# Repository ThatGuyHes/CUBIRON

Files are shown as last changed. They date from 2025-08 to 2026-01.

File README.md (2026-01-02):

# 🧊 Cubiron — DIY Tiny FDM 3D Printer

Cubiron is a DIY, compact FDM 3D printer designed for low-cost, small-format printing and hands-on learning. It's built entirely from open-source parts and the cheapest components available, using custom printable mechanics and Klipper firmware.

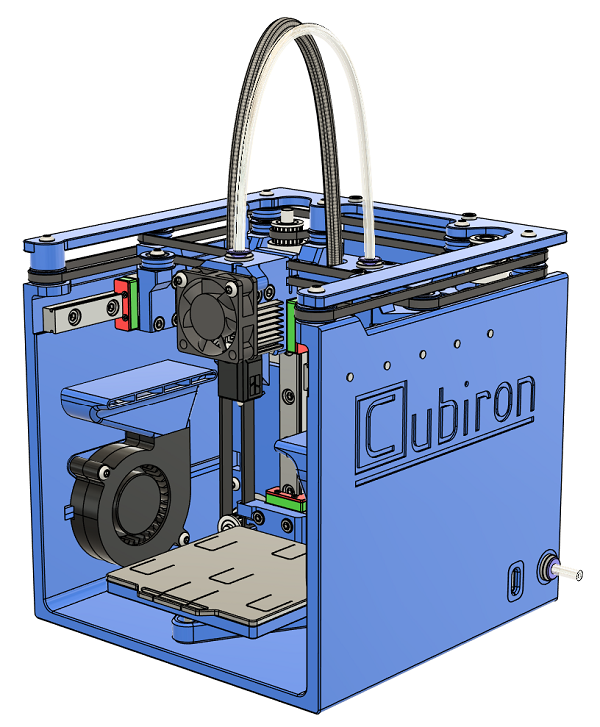
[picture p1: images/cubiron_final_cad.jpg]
Cubiron


---
## ✏️ Editor's Notes
- 03/09/2025: Added files for 1st public release.

---

## 🔧 Features

- 🔲 **70x70x65mm** Print Volume
- 📏 **144x145x148mm** Printer Size
- 🚀 Up to **500mm/s** and **10k mm/s²**
- 💧 **~10mm³ Flow** with PLA
- 🏷️ **~$270** Hardware cost
- 🧰 **1.5kg or 3.3lbs** Weight
- 🔌 **USB-C 20V**
- 💡 All 3d printed parts from **PETG**
- 📐 Includes **CAD files, BOM, STLs, printer.cfg**, and **slicer profiles**

---

## 📦 Included in this Repo

| Folder/File | Description |
|---|---|
| `CAD/` | Source and STEP files |
| `STLs/` | Printable parts |
| `firmware/` | Klipper config-files |
| `docs/` | Build manual, BOM |
| `LICENSE` | CERN-OHL-S v2 license |
| `README.md` | You're here! |

---

## 🛠 Specifications

| Feature | Value |
|---|---|
| Build Volume | 70 × 70 × 65 mm |
| Hotend Temp | Up to 230°C due to 20V |
| Drive Belts | 2GT, 3mm wide |
| Linear Rails | MGN9C - 100mm |
| Extruder | Hummingbird w/ HGX-Lite parts  |
| Hotend | BambuLab clone hotend |
| Board | Mellow Fly Micro4 |
| SBC | Raspberry Pi Zero 2W |
| Filament | PLA only |
| Print Bed | Cold, mechanical mount |
| Firmware | Klipper |
| Power Supply | USB-C PD 20V 100W |

---

## 🚧 Getting Started

0. **Read the "Printing Guidelines" section in the build guide!**
1. **3D print the STLs** in `STLs/`
2. **Follow the build guide** in `docs/build_manual.pdf`
3. **Flash Klipper** on your Pi Zero 2W
4. **Upload `printer.cfg`** and tune as needed

---

## 🙏 Acknowledgements

- Inspired by the DIY 3D printing community
- Thanks to the creators of Klipper, Hummingbird, and open hardware pioneers

---

## ❓ FAQ

<details>
  <summary>Are there any new plans for the Cubiron project?</summary>

  Not at the moment. Though I have some major changes in mind.
  Such as a 24V power supply, heated bed, and full enclosure.

</details>

---

## 💬 Contribute

This is a passion project — feedback, pull requests, remixes, and improvements are welcome!

---
## 🧾 License

Cubiron is licensed under the **CERN-OHL-S v2** license.

> This means you can use, modify, build, and sell it — but you must share changes under the same license.

📜 [Full License Text](LICENSE)



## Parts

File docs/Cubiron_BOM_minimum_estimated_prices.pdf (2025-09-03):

Part Name | Pieces | Price | Total Multiplier | Notes
LML9B Miniature Linear Rail | 5 | $7.52 | $37.60
Bambulab Clone Hotend | 1 | $8.25 | $8.25
Nema 14, 35mm long | 3 | $9.20 | $27.60
HGX-Lite hardware kit | 1 | $8.13 | $8.13
Nema 14 pancake 10t, 20mm long | 1 | $21.57 | $21.57
Mellow Fly Micro 4 | 1 | $27.66 | $27.66
RasPi Zero 2W | 1 | $23.31 | $23.31
100w USB-C PD charger 20V, 5A | 1 | $19.15 | $19.15
MP1584EN mini buck | 1 | $5.45 | $5.45
PDC004-PD 20V | 1 | $3.78 | $3.78
623-2RS 10pcs | 2 | $3.41 | $6.82
F623-RS 10pcs | 1 | $4.71 | $4.71
5015 Radial Fan 24V | 2 | $4.33 | $8.66
3010 Axial Fan 24V | 1 | $5.22 | $5.22
2GT-20T Pulley 5mm bore | 3 | $1.32 | $3.96
2GT 6mm Timing Belt 2m | 1 | $10.93 | $10.93
ECAS04 Bowden Coupling 4pcs | 1 | $1.41 | $1.41
M3x6 BHCS | 33 | | $0.00
M3x8 BHCS | 30 | | $0.00
M3x10 BHCS | 7 | | $0.00
M3x12 BHCS | 4 | | $0.00
M3x16 BHCS | 7 | | $0.00
M3x20 BHCS | 8 | | $0.00
M3x25 BHCS | 2 | | $0.00
M2.5x4 | 4 | | $0.00
M2x10 | 3 | | $0.00
M3x4 grub screw | 2 | | $0.00
M3 square nuts | 6 | $12.00 | $12.00 | * total for what's used
5x3x0.5mm spacers | 24 | | $0.00
PETG 1kg | 1 | $20.00 | $20.00
stranded wire 0.35mm² | 1 | | $0.00
stranded wire 0.25mm² | 1 | $5.00 | $5.00 | * total for what's used
spring 8x10x0.5mm 10pcs | 1 | $1.65 | $1.65
nylon braided wire sleeve 5mm, 1m | 1 | $1.75 | $1.75
PTFE tube 4mmOD, 2mmID 1m | 1 | $1.74 | $1.74
3M VHB Tape 2m | 1 | $2.36 | $2.36
Microswitch | 1 | $0.50 | $0.50
100x2.5mm zip ties 100pcs | 1 | $2.50 | $2.50
| | | $0.00
| | SUM | $271.71

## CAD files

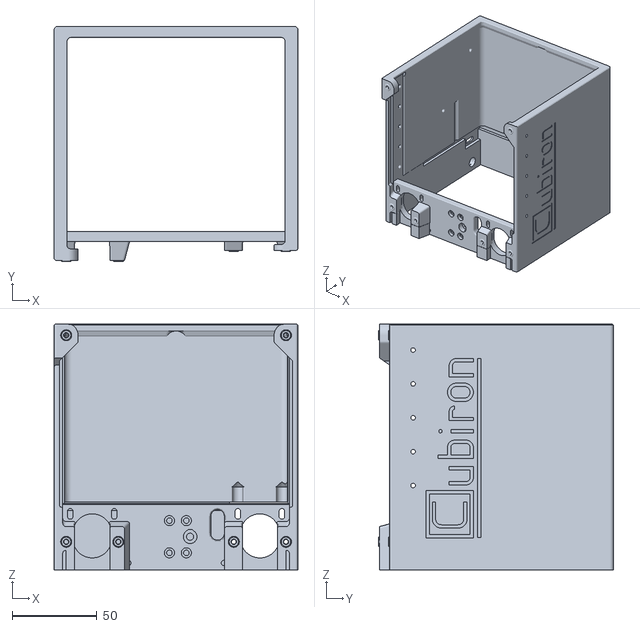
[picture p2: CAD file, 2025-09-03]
STLs/Main_frame.stl
144.1 x 138.8 x 145.0

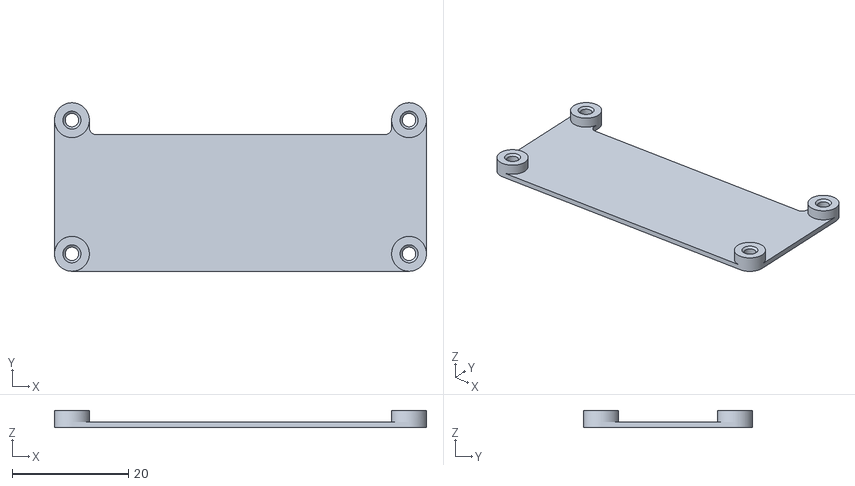
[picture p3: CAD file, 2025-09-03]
STLs/pi-zero_mount.stl
64.0 x 29.0 x 3.00

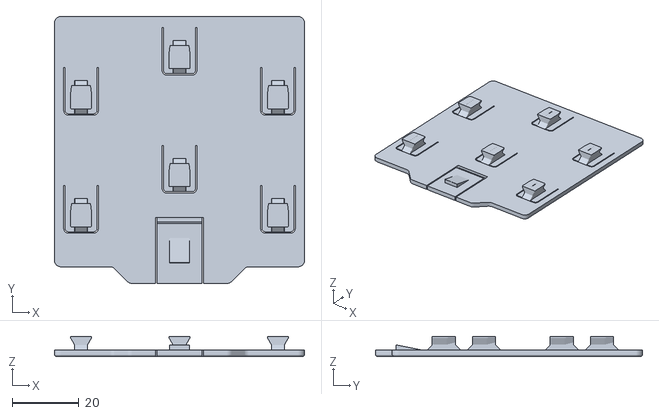
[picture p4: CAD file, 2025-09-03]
STLs/Bed-plate.stl
75.0 x 80.0 x 6.00

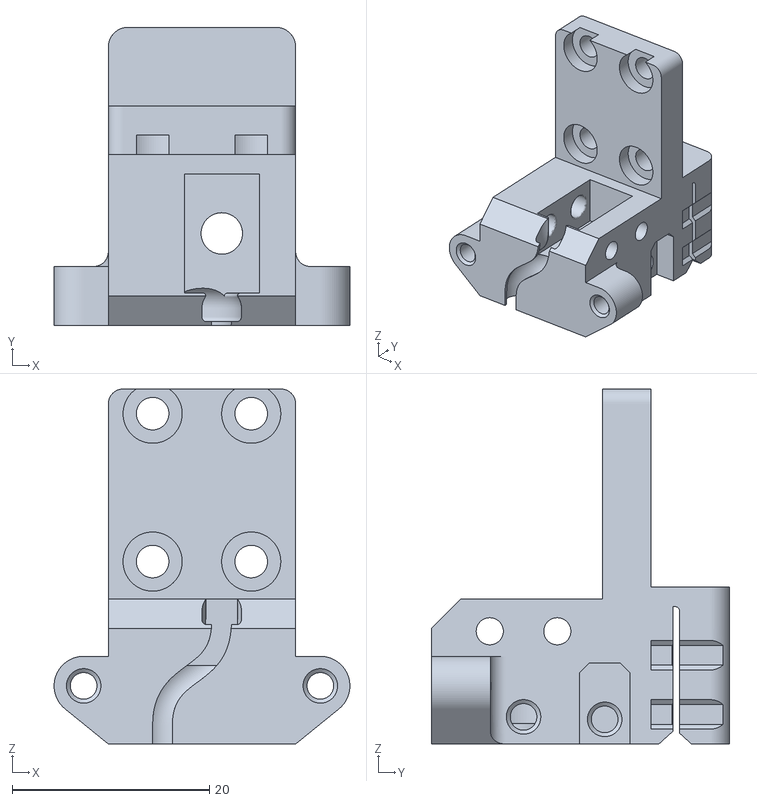
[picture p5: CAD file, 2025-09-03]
STLs/Print_head_frame.stl
30.0 x 30.3 x 36.0

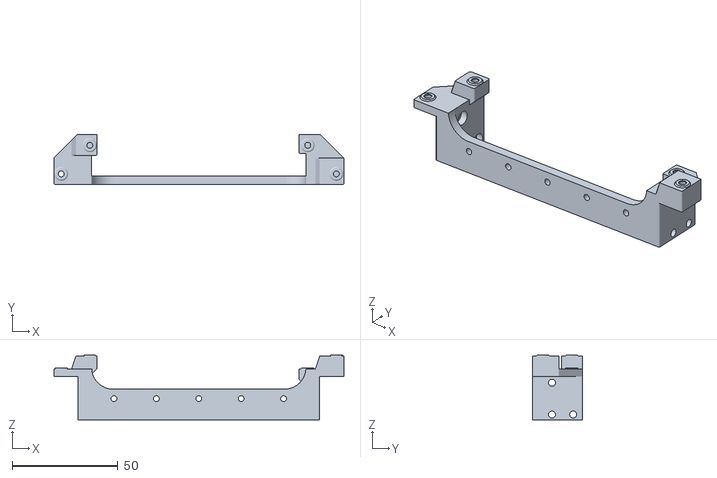
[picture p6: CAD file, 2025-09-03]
STLs/X_Beam.stl
136.8 x 23.7 x 30.5

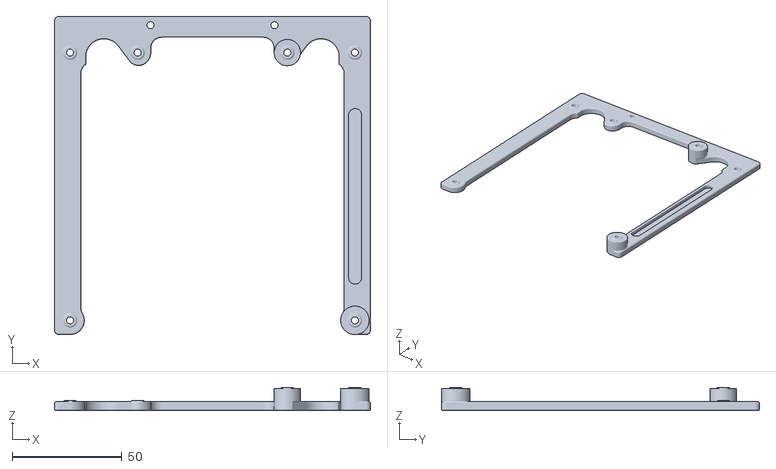
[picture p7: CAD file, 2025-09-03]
STLs/Top_Frame.stl
144.0 x 145.0 x 10.5

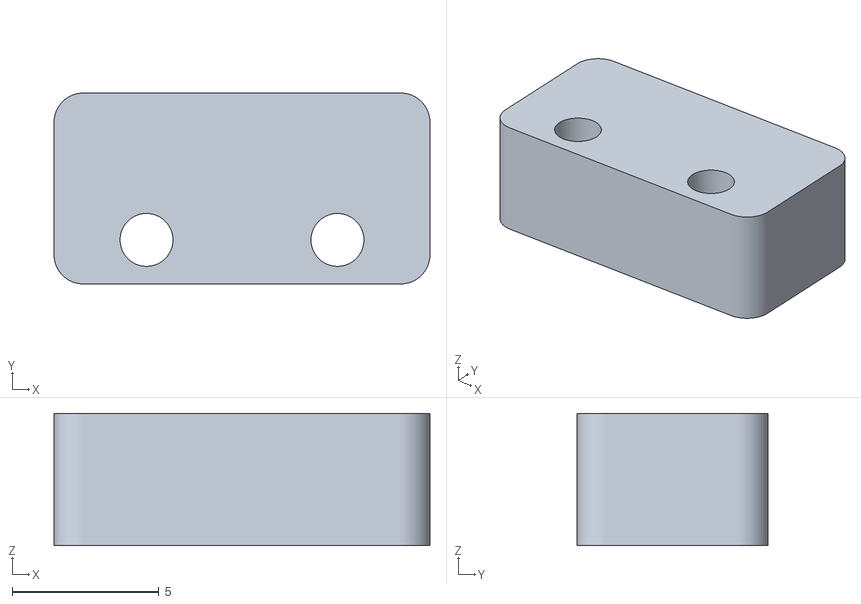
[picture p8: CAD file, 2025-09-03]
STLs/Z_endstop_mount.stl
12.8 x 6.50 x 4.50

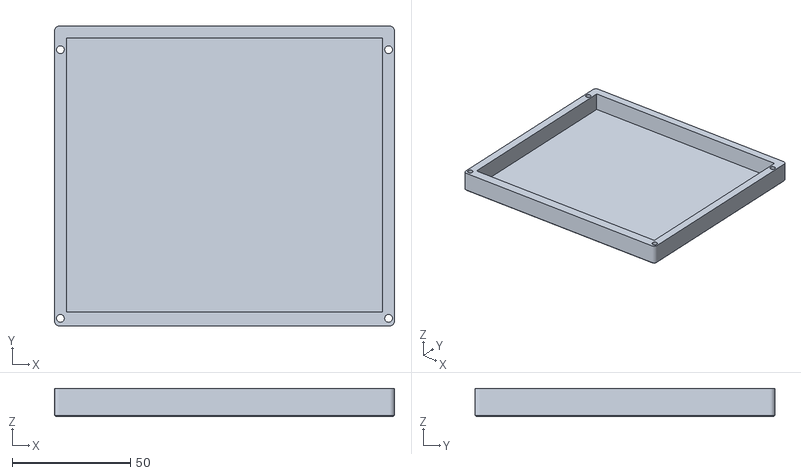
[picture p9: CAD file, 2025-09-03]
STLs/Electronics_cover.stl
144.0 x 127.0 x 12.0

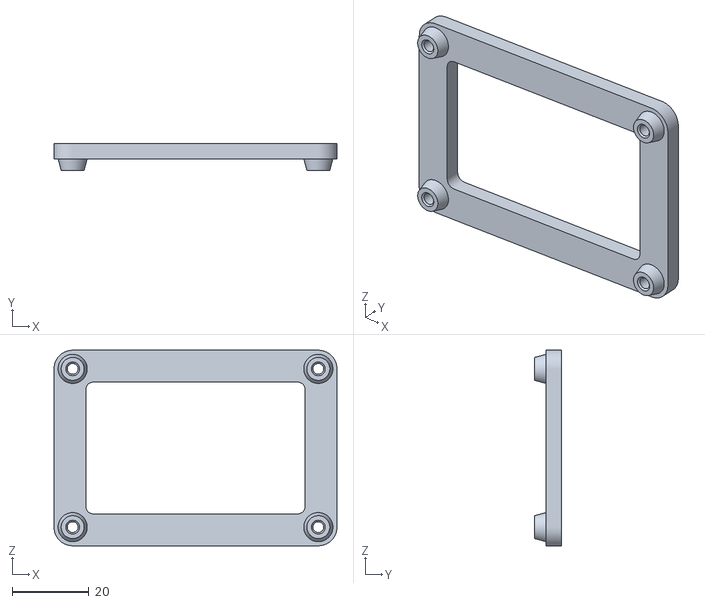
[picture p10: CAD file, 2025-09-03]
STLs/Micro4_Frame.stl
74.0 x 7.00 x 51.1

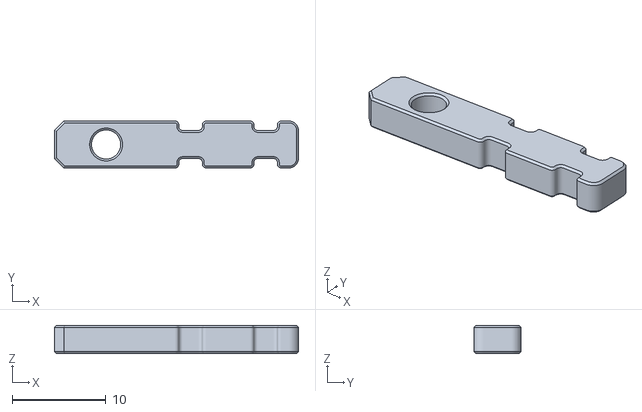
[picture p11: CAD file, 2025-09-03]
STLs/strain_reflief.stl
26.0 x 5.00 x 3.00

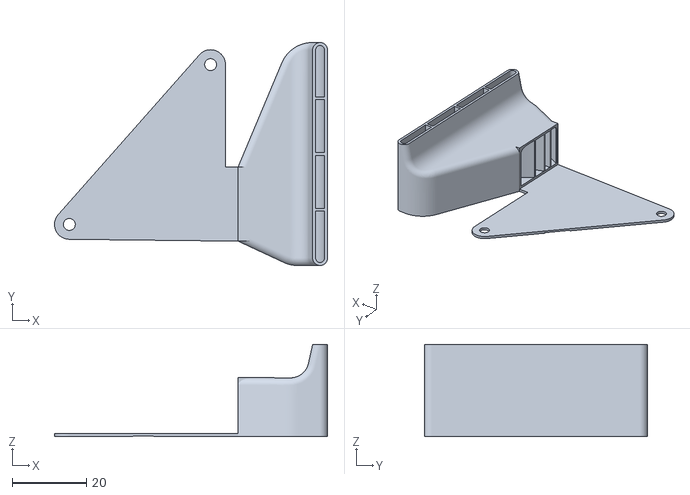
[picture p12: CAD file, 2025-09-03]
STLs/5015_fan_duct_2x.stl
73.4 x 60.0 x 24.8

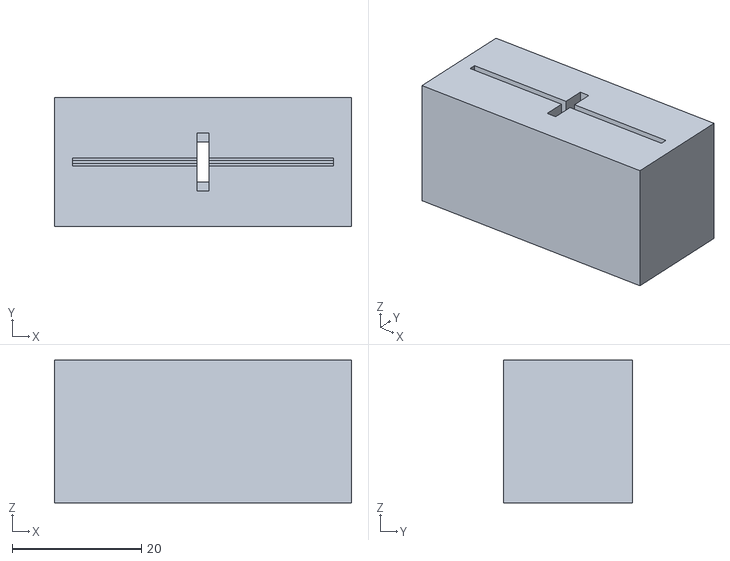
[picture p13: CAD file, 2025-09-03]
STLs/Positron 6mm to 3mm belt cutting jig.stl
46.0 x 20.0 x 22.1

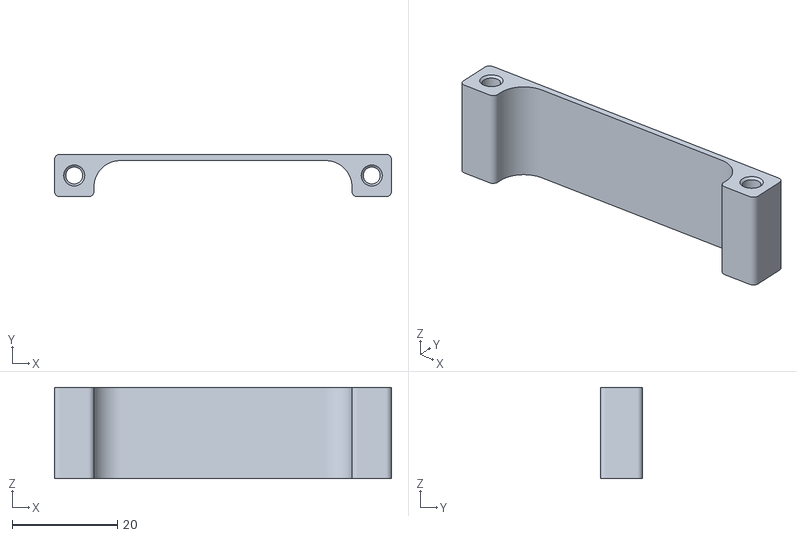
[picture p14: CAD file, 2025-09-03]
STLs/Handle.stl
64.0 x 8.05 x 17.4

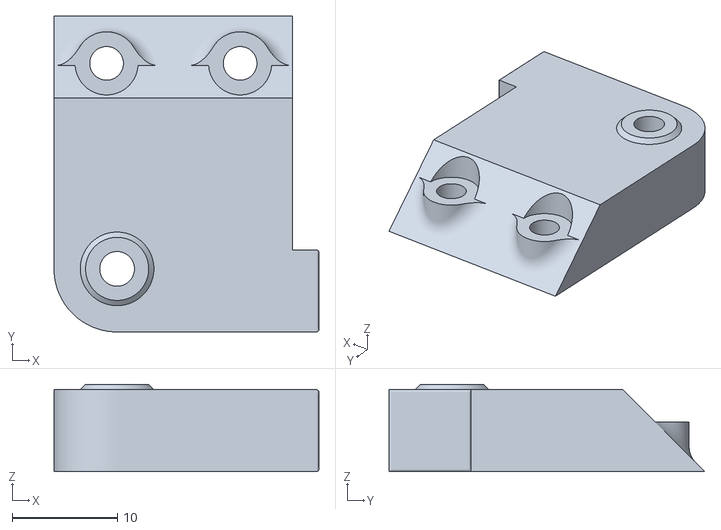
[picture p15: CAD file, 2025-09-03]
STLs/Z_Idler_Mount.stl
25.2 x 30.0 x 8.30

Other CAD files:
STLs/Z_axis_backplate.stl
STLs/X_Beam_supported.stl
STLs/Bed_Frame.stl
STLs/dc-dc-buck_cradle.stl
STLs/Bed_Frame_supported.stl
STLs/Printed_idler_24x.stl
STLs/Quickremove-bed.stl
STLs/Single-piece-idler.stl
STLs/Spacer_1mm_2x.stl
STLs/Thread_test_part.stl
STLs/USB-C-PD_cradle.stl

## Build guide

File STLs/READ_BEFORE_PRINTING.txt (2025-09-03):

**To print the Unibody main frame, please follow the instructions from the assembly manual in the "Printing Guidelines" section!**

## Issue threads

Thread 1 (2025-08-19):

Suggestions and Questions About Enclosure, Structural Strength, and Heated Bed Design

YueDayu, 2025-08-19:
Great project! I really like this kind of small 3D printer and I'm looking forward to its open-source release! However, I have a few questions:
* Is it possible to make the printer fully enclosed and add a built-in air filtration system?
* Is the strength of the front section sufficient? Would a crossbeam be needed for reinforcement?
* It looks like there is space for a heated bed. Is it possible to use a PCB to make an aluminum plate heated bed?

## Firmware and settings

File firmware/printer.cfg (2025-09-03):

####################################################################################
#                                         3D MELLOW                                #
####################################################################################
## Fly micro documentation: http://mellow.klipper.cn/#/board/fly_micro/README
## Fly micro schematic: http://mellow.klipper.cn/#/board/fly_micro/schematic
## FLY Official Taobao Store: https://shop126791347.taobao.com/shop/view_shop.htm?spm=a230r.1.14.4.1a4840a8hyvpPJ&user_number_id=2464680006
## For after-sales service, please contact Taobao customer service
## FLY After-sales Technical Support Group: 621032883
## FLY#RRF Firmware Group: 786561979

#####################################################################
#      Notes
#####################################################################
##***Things to change/check:***
## MCU path                                [mcu] 
## Printer movement range                   xyz position   
## Thermistor type                          [extruder] and [heater_bed]
## Z endstop position                       [safe_z_home] 
## Z endstop offset                         [stepper_z] 
## PID tuning                               [extruder] and [heater_bed] 
## Extruder motor steps fine-tuning         [extruder] 

#####################################################################
#      file invocation
#####################################################################
#[include fluidd.cfg]          # FLUIDD include file.
[include mainsail.cfg]        # MAINSAIL include file.
#Choose the file you need to use

#####################################################################
#      Master ID Configuration
#####################################################################
[mcu]
serial:
### To check USB firmware id: ls /dev/serial/by-id/*
### Replace /dev/serial/by-id/usb-Klipper_rp2040_MELLOW-if00 with your id
#canbus_uuid: 114514114514
### To check CAN firmware id: ~/klippy#env/bin/python ~/klipper/scripts/canbus_query.py can0
### For CAN, replace serial with canbus_uuid: and add the id

#####################################################################
#      Temperature monitoring
#####################################################################
[temperature_sensor Micro4]        # Show board temperature
sensor_type: temperature_mcu
#####################################################################
# [temperature_sensor lite2]       # Host temperature
# sensor_type: temperature_host
[temperature_sensor raspberry_pi]
sensor_type: temperature_host
min_temp: 10
max_temp: 100
#####################################################################
#      Kinematics and acceleration
#####################################################################
[printer]
kinematics: corexy
max_velocity: 500
max_accel: 5000
max_z_velocity: 15
max_z_accel: 300
square_corner_velocity: 6.0

[exclude_object]

#####################################################################
#      X/Y Stepper Settings
#####################################################################

[stepper_y]
## Refer to https://docs.vorondesign.com/build/startup/#v0
step_pin: gpio26
dir_pin:gpio25                                    # Check motor direction in link above. If inverted, add a ! before gpio3 
enable_pin:!gpio27
rotation_distance: 32 #40 for 20T pulleys
microsteps: 32
full_steps_per_rotation: 200                    # Set to 400 for 0.9° stepper motor, 200 for 1.8°
endstop_pin: tmc2209_stepper_y:virtual_endstop
position_endstop: -2
position_max: 70
position_min:-2
homing_speed: 20                                # For sensorless homing, do not exceed 40mm/s   
homing_retract_dist: 0

[tmc2209 stepper_y]
uart_pin:gpio9
uart_address:2
interpolate: True
run_current: 0.4
sense_resistor: 0.110
stealthchop_threshold: 999999                        # Set to 999999 to enable stealthchop, 0 for spreadcycle
diag_pin: ^gpio15
driver_SGTHRS: 65

[stepper_x]
## Refer to https://docs.vorondesign.com/build/startup/#v0
step_pin:gpio1
dir_pin:gpio0                                    # Check motor direction in link above. If inverted, add a ! before gpio0
enable_pin:!gpio2
rotation_distance: 32 #40 for 20T pulleys
microsteps: 32
full_steps_per_rotation: 200
endstop_pin: tmc2209_stepper_x:virtual_endstop
position_endstop: -1
position_max: 70
position_min:-1
homing_speed: 20 
homing_retract_dist: 0

[tmc2209 stepper_x]
uart_pin:gpio9
uart_address:1
interpolate: True
run_current: 0.4
sense_resistor: 0.110
stealthchop_threshold: 999999
diag_pin: ^gpio14
driver_SGTHRS: 60

#####################################################################
#   Z Stepper Settings
#####################################################################
[stepper_z]
## Refer to https://docs.vorondesign.com/build/startup/#v0
step_pin: gpio6
dir_pin: gpio3                                    # Check motor direction in link above. If inverted, add a ! before gpio25
enable_pin: !gpio7
rotation_distance: 40
microsteps: 32
endstop_pin: ^gpio13
position_endstop: 65
position_max: 65
position_min: -1.5
homing_speed: 20
second_homing_speed: 3.0
homing_retract_dist: 3.0

[tmc2209 stepper_z]
uart_pin:gpio9
uart_address:0
interpolate: True
run_current: 0.4
sense_resistor: 0.110
stealthchop_threshold: 999999

#####################################################################
#   Extruder
#####################################################################
[extruder]
## Type of sensor # common thermistors are (Generic 3950, ATC Semitec 104GT#2)
sensor_type: ATC Semitec 104GT-2
sensor_pin: gpio28

step_pin: gpio23
dir_pin: !gpio22
enable_pin: !gpio24
rotation_distance: 5.7
## rotation_distance = The original rotation_distance * actual extrusion length / requested extrusion length.
microsteps: 16
full_steps_per_rotation: 200    
nozzle_diameter: 0.400
filament_diameter: 1.75
heater_pin: gpio20
min_temp: 0
max_temp: 250
max_power: 1
min_extrude_temp: 150
pressure_advance: 0.2
pressure_advance_smooth_time: 0.040
#max_extrude_only_distance: 200.0   # If extrusion error, comment this, but it's better to re-slice
#Nozzle PID tuning command:  "PID_CALIBRATE HEATER=extruder TARGET=245
control: pid
pid_kp: 26.213
pid_ki: 1.304
pid_kd: 131.721
step_pulse_duration: 0.000004

[tmc2209 extruder]
uart_pin: gpio9
uart_address: 3
interpolate: True
run_current: 0.5
sense_resistor: 0.110
stealthchop_threshold: 999999

#####################################################################
# Fan Control
#####################################################################
[fan]
pin: gpio17
max_power: 1.0
kick_start_time: 0.5                                                # Increase if your fan does not start
off_below: 0.13
cycle_time: 0.010
#####################################################################
[heater_fan hotend_fan]
pin: gpio16
max_power: 1.0
kick_start_time: 0.5
heater: extruder
heater_temp: 50.0

#####################################################################
# Homing and Gantry Adjustment Routines
#####################################################################

[idle_timeout]
timeout: 1800

[homing_override]
axes: xyz
set_position_z: 0
set_position_x: 0
set_position_y: 70
gcode:
  CUSTOM_HOME

[gcode_macro CUSTOM_HOME]
gcode:
  G90
  G0 Z5 F600
  {% set home_all = 'X' not in params and 'Y' not in params and 'Z' not in params %}

  {% if home_all or 'X' in params %}
      _HOME_X
  {% endif %}

  {% if home_all or 'Y' in params %}
      _HOME_Y
  {% endif %}

  {% if home_all or 'Z' in params %}
      _HOME_Z
  {% endif %}

#[safe_z_home]                     ## Only needed if you are using V0.0 or V0.1 Z endstop location
#home_xy_position: 35,35
#speed: 20.0
#z_hop: 2

## To be used with BED_SCREWS_ADJUST
#[bed_screws]
#screw1: 60,5
#screw1_name: front screw
#screw2: 5,115
#screw2_name: back left
#screw3: 115,115
#screw3_name: back right
#Probe_height: 0.1

#####################################################################
# Macros
#####################################################################

[gcode_macro PRINT_START]
#   Use PRINT_START for the slicer starting script - please customize for your slicer
gcode:
    G28                            ; home all axes
    G90                            ; absolute positioning    
    G1 Z20 F3000                   ; move nozzle away from bed
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

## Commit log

2025-08-11 Create CAD
2025-09-03 Add STL files
    [5015_fan_duct_2x.stl, Bed-plate.stl, Bed_Frame.stl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]
2025-09-03 Add CAD file
2025-09-03 Add cfg file
    [printer.cfg]
